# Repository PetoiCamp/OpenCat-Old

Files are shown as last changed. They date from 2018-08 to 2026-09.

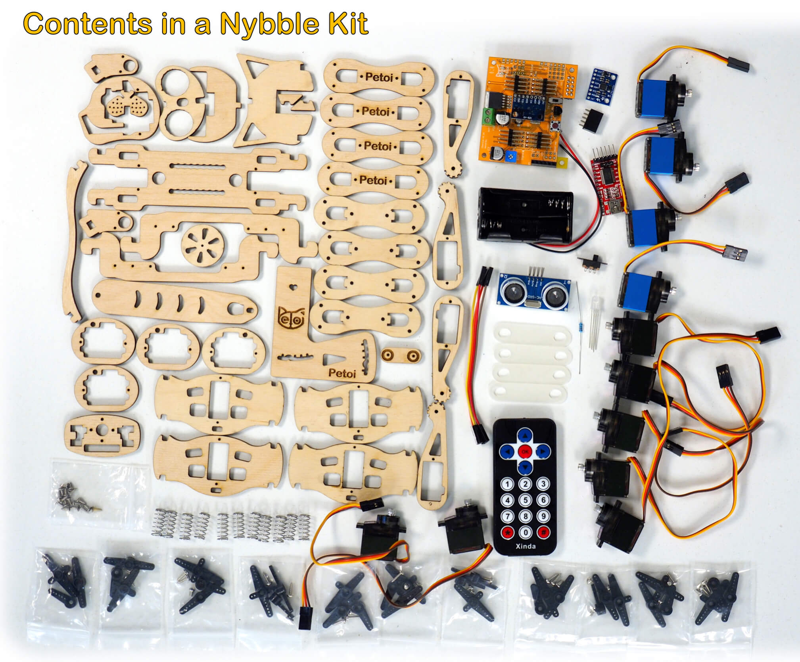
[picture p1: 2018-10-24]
Resource/Images/nybbleParts.jpg

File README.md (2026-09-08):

# OpenCat

**This repository for Nybble is too redundent with large image files and is now obsolete. Please visit our [new repository for OpenCat](https://github.com/PetoiCamp/OpenCat) that works for both Nybble and Bittle! For the latest OpenCat robots (Bittle X, Nybble Q), see [OpenCatESP32](https://github.com/PetoiCamp/OpenCatEsp32-Quadruped-Robot), or buy [Bittle X on Petoi.com](https://www.petoi.com/shop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).**





--

This is the repository for OpenCat project. 

The goal is to collaborate talents for this cute quadruped mini robot kit. It's still a complex system only for skilled makers, yet we want to share it with the public by mass production and bringing down the cost. 

OpenCat robots are used for hands-on **physical AI education** and real-world **physical AI applications** — from K-12 robotics classrooms to university research labs — not just screen-based coding exercises.

## Quaddle mini robot dog — launching on Kickstarter Sept 2, 2026


[Quaddle](https://www.kickstarter.com/projects/petoi/quaddle-open-source-desktop-robot-kit/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) is Petoi's newest quadruped, **going live on Kickstarter Sept 2, 2026** — a mini desk robot built on the same OpenCat lineage as Bittle and Nybble.

- Full quadruped running on just **4 servos** instead of the usual 8–12, which forces genuinely different gait-design and leg-coordination solutions to still get all four legs walking, running, and balancing
- Position-feedback servos — readable, not just drivable — which is what makes **Puppet Mode** possible: hand-guide the legs and record a motion directly, no code required
- 3D-printable shells and mounts for customization
- Same open platform this codebase's lineage already supports for gait research, reinforcement learning (RL), and sim2real work — a hands-on physical AI platform, not a toy version of the idea
- Try it in the [online simulator](https://www.petoi.com/pages/quaddle-robot-dog-simulator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) before it ships

**Source code is not yet public.** It's an upgraded version of the OpenCat project. Its ESP32-S3 code structure is closer to [OpenCatESP32](https://github.com/PetoiCamp/OpenCatEsp32-Quadruped-Robot), which already powers thousands of Bittle X and Nybble Q robots in the field, than to this legacy repo. We plan to open source it before Quaddle delivery.

- Watch [r/petoi](https://www.reddit.com/r/Petoi/) for the open-source announcement
- [Get notified on Kickstarter](https://www.kickstarter.com/projects/petoi/quaddle-open-source-desktop-robot-kit/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) when it goes live
- Check out the [Quaddle Hugging Face page](https://huggingface.co/petoi/quaddle)

## About the Founder & Track Record

Inspired by Boston Dynamics' Spot, [Dr. Rongzhong Li](https://www.linkedin.com/in/rongzhongli/) started OpenCat in his dorm at Wake Forest University in 2016. The goal was straightforward: make agile quadruped robots affordable and hackable enough for researchers, educators, and makers — not just well-funded labs.

Since then:
- **30,000+ robots shipped**, cumulative across all channels
- **60+ countries**
- **$1M+ raised** across two prior Kickstarter and Indiegogo campaigns
- **20+ academic papers** cite the platform — see [Research Spotlight](https://www.petoi.com/pages/robotics-research-and-academic-applications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)
- One of the most-starred open-source quadruped robot projects on GitHub

Follow the project:

- [YouTube](https://www.youtube.com/@petoicamp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)
- [Twitter](https://twitter.com/petoicamp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)
- [Instagram](https://www.instagram.com/petoicamp/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)
- [Facebook](https://www.facebook.com/PetoiCamp/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)
- [LinkedIn](https://www.linkedin.com/company/petoi/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)
- [TikTok](https://www.tiktok.com/@petoicamp/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)

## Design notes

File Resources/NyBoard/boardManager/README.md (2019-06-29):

# Arduino IDE Board Manager

Adds the NyBoard board definition through the *Arduino 1.6.4 (and later)* board manager rather then editing `boards.txt` directly as described at https://github.com/PetoiCamp/OpenCat/wiki/Software-setup.

## Usage

1. Open the Arduino IDE application

2. Open the `Preferences...` panel

3. In the `Additional Boards Manager URLs` field, add `https://raw.githubusercontent.com/PetoiCamp/OpenCat/master/Resources/NyBoard/boardManager/package_petoi_nyboard_index.json`. If there are already URLs listed in this field, separate them with commas or click on the icon next to the field to open up an editor and add this URL to a new line.

4. Click on the `OK` button to close the `Preferences...` panel (you may need to do this for the `Additional Boards Manager URLs` editor first, if you opened it up in the previous step)

5. Open the `Boards Manager...` window with the `Tools` -> `Board: XXXX` -> `Boards Manager...` menu item.

6. In the `Filter your search...` field, type `NyBoard`

7. Select the entry and click on `Install`

8. Click on the `Close` button

9. Select `ATmega328P (5V, 20 MHz) NyBoard` from the `Tools` -> `Board: XXXX` menu and enjoy!

## Updating the Board Definition

This section should not be necessary for most users and is included only for reference. As this is my first foray into using the Boards Manager, these steps may change slightly as necessary and I will try to keep this updated for reference.

1. Any additions to the `NyBoard-0.1` directory or changes to `NyBoard-0.1/boards.txt` require the following additional steps (update version numbers as appropriate):

  A. The archive file `NyBoard-0.1.x.tar.bz2` needs to be rebuilt

    i. Mac or Linux, use: `tar -cjf NyBoard-0.1.x.tar.bz2 NyBoard-0.1`

    ii. *TBD* need Windows equivalent

  B. Update `pacakge_petoi_nyboard_index.json` as follows:

    i. Update the `"version"` field to match the new version number (e.g. "0.1.x")

    ii. Update the `"url"` and `"archiveFileName"` fields to match the new archive name.

    iii. Update the `"size"` field to match the new archive file size

    iv. Update the `"checksum"` field to match the new archive file

      a. Mac or Linux use: `openssl dgst -sha256 NyBoard-0.1.x.tar.bz2` to get this value

      b. *TBD* need Windows equivalent

  C. Alternatively, if you wish to keep multiple versions of the board definition around, you can copy the entire entry in `"platforms"` (lines 12 - 31), add a comma after the closing brace of the last entry in `"platforms"`, paste the copy to the next line (before the closing bracket) and make the changes in **B** to the new entry.

2. Changes to the other informational fields of `pacakge_petoi_nyboard_index.json` should not require rebuilding the archive or modifying the file size or checksum values.

## Reference

* https://github.com/PetoiCamp/OpenCat/wiki/Software-setup
* https://github.com/arduino/Arduino/wiki/Arduino-IDE-1.6.x-package_index.json-format-specification

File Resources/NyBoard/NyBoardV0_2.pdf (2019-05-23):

## User Manual of NyBoard V0_2

Introduction

- NyBoard is a motion control board for the robotic kitten named Nybble, the first product of OpenCat project. It’s also compatible for other robots following OpenCat framework. Taking ATmega328P as the core processor, NyBoard runs at 20MHz clock to control 16 independent PWM servos with real-time adaption.
- The size of NyBoard is only 65×56mm. Components on the board are carefully laid out to precisely fit the contour of Raspberry Pi 3B and later models. There is a 2×5 socket connecting the NyBoard and Pi, which includes the power, UART, reset, I

2
C
and I²
C reference. Through it, the NyBoard can power Pi and communicate with Pi.
- NyBoard can accept 6~9V power inputs. Be careful with the polarity when connecting your power supply to NyBoard’s battery socket. There’s “+” and “-” besides the socket. Reversed connection may damage your NyBoard!
- To isolate voltage fluctuation caused by servos’ movement, NyBoard provides two independent power management. One supplies a stable 5V power to the chips, the other supplies an adjustable voltage (4.5-7.5V) to suit most models of servos. To ensure safety during operation, please do not connect the servo to NyBoard first. Check the rated voltage of the servo, use a voltmeter to monitor the output for servos and adjust the potentiometer to obtain a desired voltage.
- NyBoard has a built-in I²
C network with ATmeg328P working as master and other peripherals as slaves, including the PWM/servo driver, the 6-Axis motion sensor and external EEPROM. NyBoard also provides a jumper switch for users to choose whether ATmega328p or Pi (or another AI chip) will be the master of the I² C
network. We hope that by providing alternatives, users can explore and find the best configuration for their projects.

Features

- Core processor: ATmega328P working at the frequency of 20MHz.
- Power input: DC 6-9V
- Power output: Two independent power supplies, 5V to chips (3A peak), 4.5-7.5V adjustable voltage to servos (5A peak). Dial counterclockwise will increase the voltage for servos. The stable voltage range will shift with different input voltage. Due to the resistance in chip, the maximum output will be lower than raw input. Stable 7.5V can only be achieved with 9V input. Try to use the lowest voltage that can complete your motion requirement, to reduce the wearing of your servo’s gears, and increase both circuit stability and battery life.

- On NyBoard V0_2, there’s a jumper switch (SW3). You can choose to power the metal servos included in Nybble kit by batteries directly to achieve the best performance. Don’t power cheap plastic servos directly by battery!
- LED power indicators: 2 LEDs, blue for the chip, yellow for the servos.
- Servo: 16 channel PWM outputs.
- Grouped 2x3 SPI port for burning bootloader or uploading sketches.
- FTDI port: 1×6 socket for connecting the 5V serial-to-USB translator. The long pin legs allow bending to the other side of the board or other directions for convenient access.
- Motion sensor port: connects to GY521-MPU6050, which is centered on the board. Interrupt is connected to pin D2. Note: MPU6050 should always be facing up for measurements using default library (I2Cdevlib).
- 2×5 Socket to Pi: connects to 5V power, I²
C, I

2
C reference, 3.3V UART and reset.
- I

2

C switch (SW2): choose ATmega328P or Pi as the master of the I²
C network.
Note that the REF pin in the 2x5 socket must be connected to the Vcc of the master board as a reference for the level converter chip.
- Additional I²
C ports: 3x I

2
C ports directly connected to the 2x5 socket of Pi, leveled at 3.3V. (It’s not connected to the ATmega328 ’s I

2
C network)
- EEPROM: 8KB. Page write limit is 32 Bytes.
- Additional D/A pins: 3×4 socket with unused pins of ATmega328P
- Additional 5V/GND pins: power other peripherals
- Additional capacitor port below C3: allow more stable output for intense motion
- IR receiver: Receiving frequency 38KHz (using Arduino digital pin D4). The long pins allow bending to the best receiving orientation.
- Buzzer: Active (using Arduino PWM pin D5)
- Reset button: Reset the NyBoard
- Battery voltage detector: can be programed to alarm when battery is low (using Arduino analog pin ADC0)
- PCB: double-layer, 65×56mm

Ports and Specification

The tables are ordered as the squares on the board, from left to right, top to bottom:

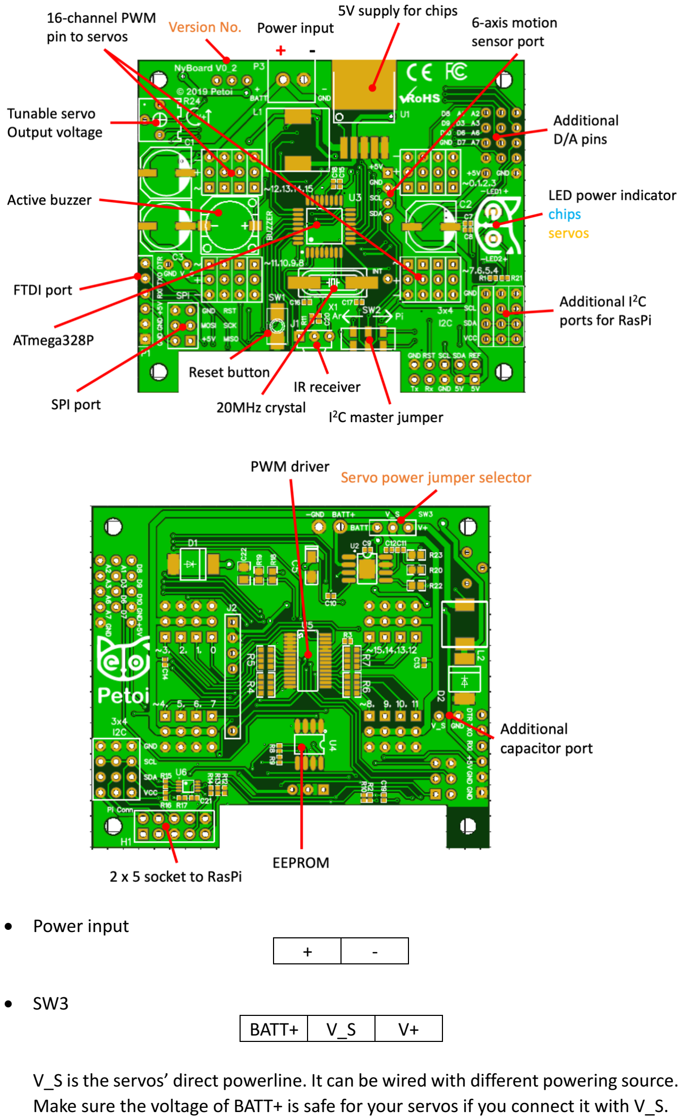
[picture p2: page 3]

- Power input
+ -
- SW3
BATT+ | V_S | V+

V_S is the servos’ direct powerline. It can be wired with different powering source. Make sure the voltage of BATT+ is safe for your servos if you connect it with V_S.

V+ comes from the stepdown chip. It has regulated but limited output.

- 16 channel PWM pin to servos (NyBoard V0_2)
GND | | GND
+ | | +
12 | 13 | 14 | 15 | 0 | 1 | 2 | 3
11 | 10 | 9 | 8 | 7 | 6 | 5 | 4
+ | | | | +
GND | | | | GND
- FTDI port
DTR
TXO
RXI
+5V
GND
GND
- SPI port
GND | RST
MOSI | SCK
+5V | MISO
- IR receiver
OUT | GND | +5V
- 6-Axis motion sensor port
Mark on NyBoard | Corresponding pins on GY521
+5V | VCC
GND | GND
SCL | SCL
SDA | SDA
/ | /
/ | /
/ | /
INT | INT
- I

2
C jumper switch
Dial up to select ATmega328P, dial down to select Pi (or another AI chip)

- Pre-defined pins (~ supports PWM)
Interrupt | IR receiver | Buzzer | MOSI | MISO | SCK
D2 | D4 | D5 ~ | D11 ~ | D12 | D13
- Additional D/A pins
D8 | ADC1 | ADC2
D9 ~ | D3 ~ | ADC3
D10 ~ | D6 ~ | ADC6
GND | D7 | ADC7
+5V | | GND
Recommended usage is using (D8, D9, D10, GND) for the ultrasound sensor, and (A2, A3, A6, A7) for optional foot contact sensors. You can also find other combinations in one row/column for convenient interfacing (2 Digital + 1 Analog, 2 Analog + 1 Digital, GND + digital + Analog, etc.)
- Additional I²
C ports (the voltage of VCC is equal to REF)
GND | GND | GND
SCL_P | SCL_P | SCL_P
SDA_P | SDA_P | SDA_P
VCC | VCC | VCC
- Socket to Pi
REF | SDA_P | SCL_P | RST | GND
+5V | +5V | GND | TXD | RXD

May 21st, 2019

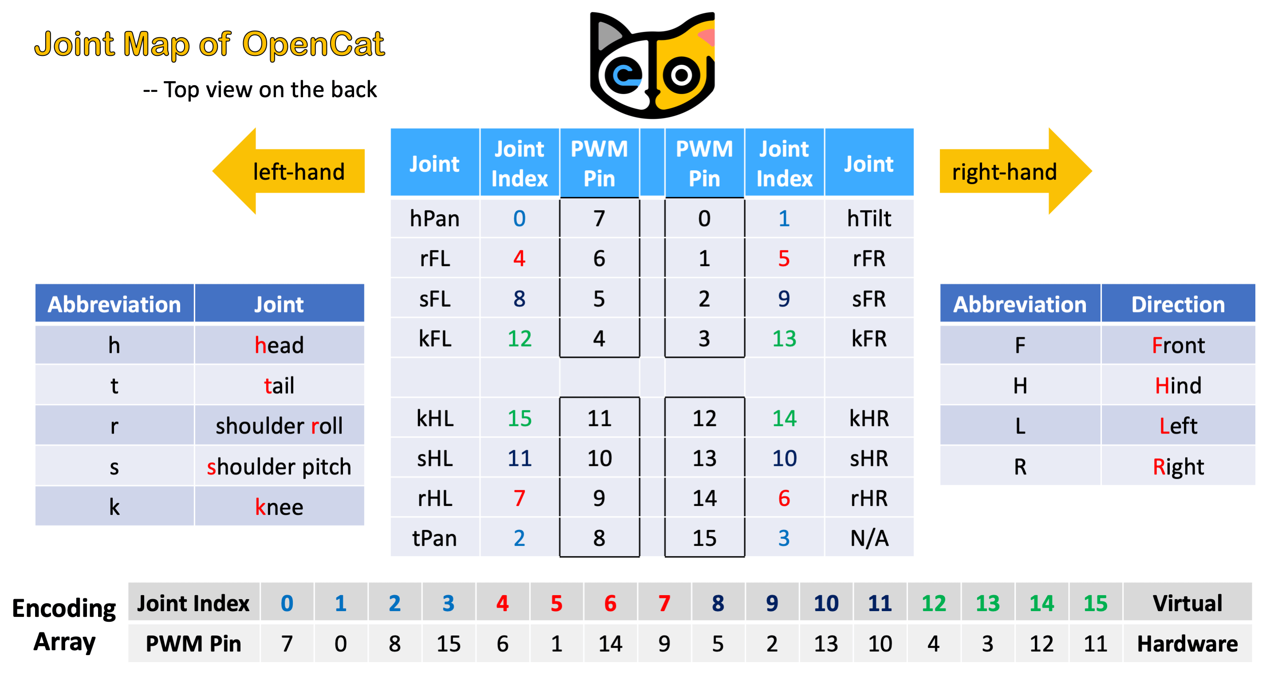
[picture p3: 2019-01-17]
Resources/Images/jointMap.png

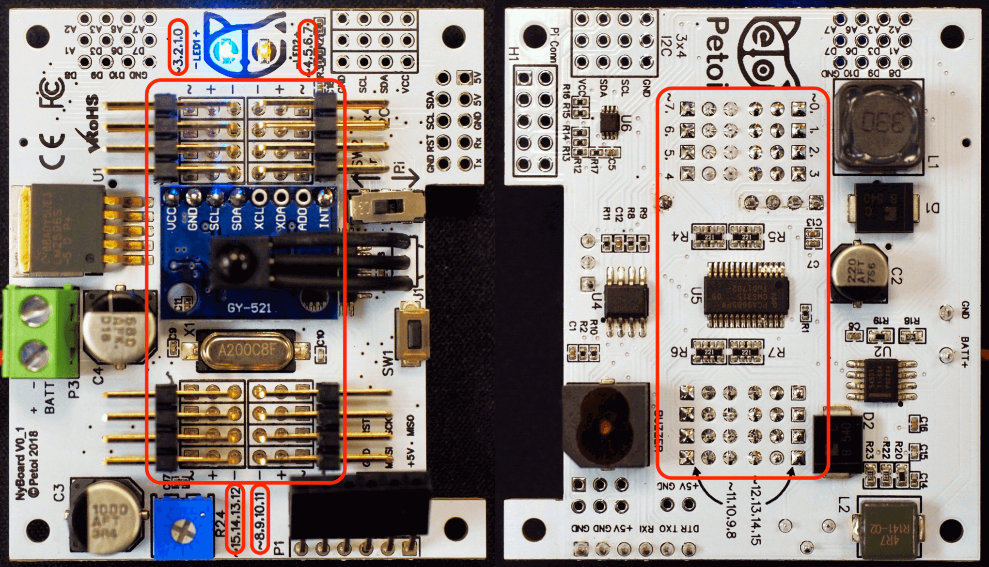
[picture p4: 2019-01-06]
Resources/Images/v0_1.png

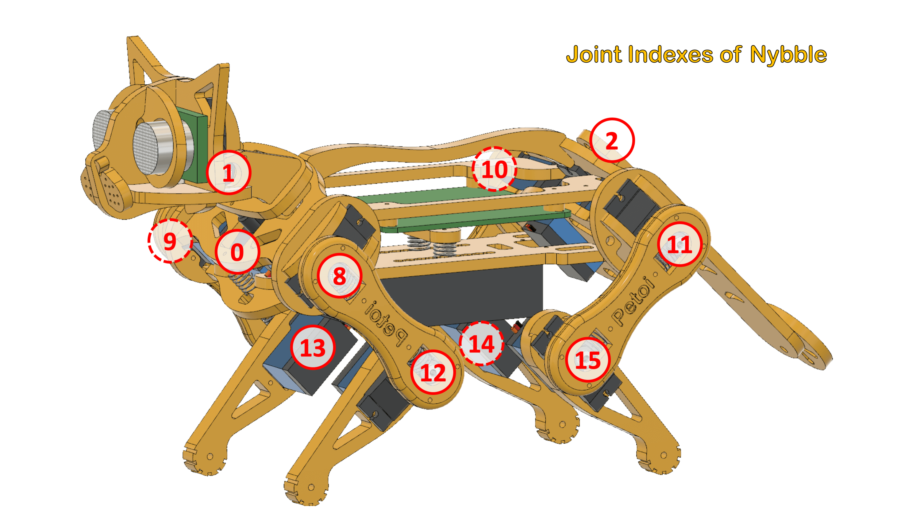
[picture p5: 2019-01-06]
Resources/Images/jointIndexNybble.png

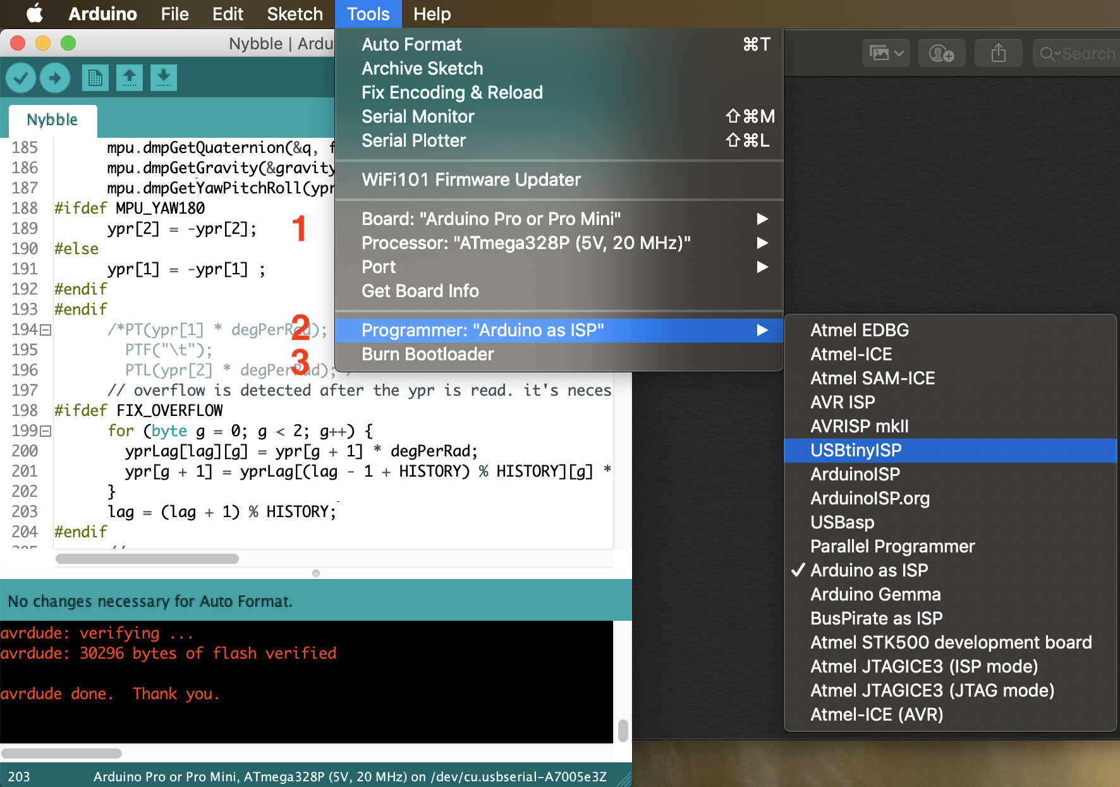
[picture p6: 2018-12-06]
Resources/Images/burnBootloader.png

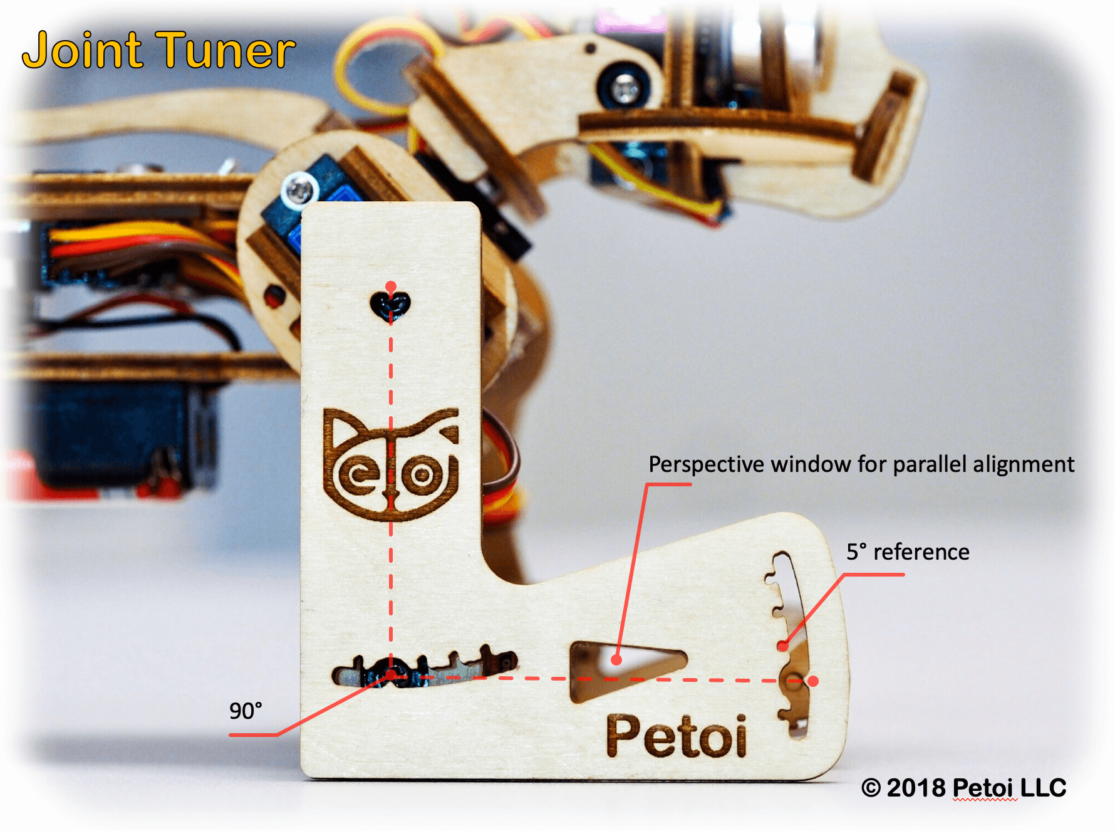
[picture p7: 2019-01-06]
Resources/Images/LTuner.png

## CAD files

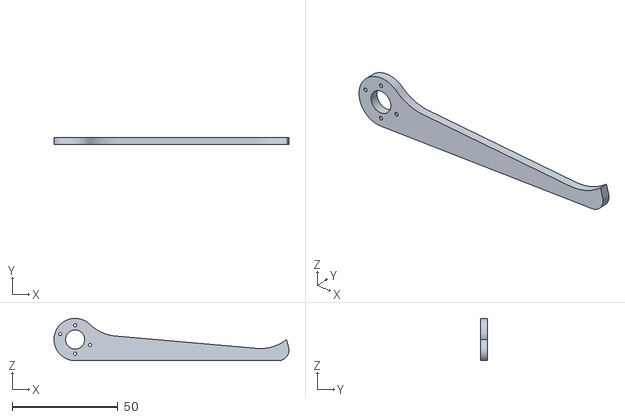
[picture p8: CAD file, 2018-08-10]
ModuleTests/testServo/servoTorqueArm.stl
111.2 x 3.50 x 20.0

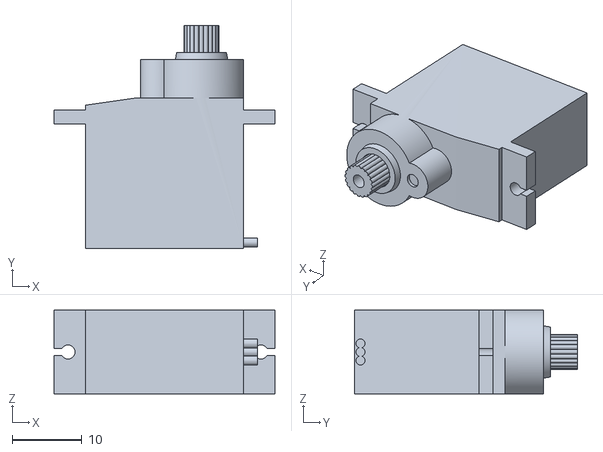
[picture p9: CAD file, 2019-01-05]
Resources/STL/mg90d.stl
31.6 x 31.9 x 12.0

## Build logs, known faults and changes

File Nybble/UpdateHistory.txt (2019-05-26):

Update History
-------------------------
May.25, 2019
* OpenCat.h
- Changed printList() to concatenate strings before printing them to serial. Reduced communication. 

* ardSerial
- Implemented serial communicator in Python on the Pi side. Almost equivalent to Arduino IDE's serial monitor. 

May.23, 2019

* Nybble.ino
- Implemented serial parser for token 'i' and 'l'.
- Converted the serial parser from if...else to switch cases.
- Updated serialProtocol.png for the actual codes of 'i' and 'l'.
- Lowered the battery voltage watcher's threshold.
- Changed the pin "0" in attachInterrupt() to "#define INTERRUPT 0" in OpenCat.h.

May. 4, 2019

* Nybble.ino
- Added a new token 'j' to show the list of current joint angles. 
  It can be used after multiple 'm' commands to define a new posture. 
- Added a key ("tb" on remote) to turn off the Gyro and boost running speed for 4 cycles.
- Added a greeting behavior ("hi" on remote).

Apr.22, 2019

*Nybble.ino
- Added offsetLR and related logic to let Nybble look around when walking and turning
- Added battery voltage reading at the beginning of loop().
  If the voltage drops below certain value, the program will pause by meow() to recharges the capacitor.
  It will reduce the abnormal rotation of servos and chances of board reset.
- Redefined the key map of infrared remote.

* OpenCat.h
- Added preprocessor #DEVELOPER to hide some detailed debugging information and libraries.
- Moved "#define NYBBLE" from OpenCat.h to Instinct.h 
- Changed yprLag from int8_t (angles) to float (radian) to reduce calculations for degree/radian conversion
- Changed RollPitchDeviation from int8_t (angles) to float (radian).
- Changed the type of adaptiveParameterArray from float to int8_t. Adjusted values.

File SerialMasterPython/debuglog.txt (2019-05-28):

Testing command-line inputs

    ./ardserial.py c->works

    ./ardserial.py c15-> gives c1   5..which might be a problem

    ./ardserial.py m1 75, m 1 75 also work

    ./ardserial.py u-> works

    ./ardSerial.py i 1 9 9 13 13 1-> works

    ./ardserial.py u 0 7->works

Testing wrapper() with schedule

    The cases with ints arrays work

    Single letter cases seem to work (although things 'ktr' and 'c8' might have issues)

    string arrays might be an issues

    Even though the last process is a d, the light doesnt turn off.

    Beep works

There might be a bug in 'k'

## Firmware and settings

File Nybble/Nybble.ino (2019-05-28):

/* Main Arduino sketch for Nybble, the walking robot kitten.
   Updates should be posted on GitHub: https://github.com/PetoiCamp/OpenCat

   Rongzhong Li
   Aug. 27, 2018
   Copyright (c) 2018 Petoi LLC.

   This sketch may also includes others' codes under MIT or other open source liscence.
   Check those liscences in corresponding module test folders.
   Feel free to contact us if you find any missing references.

   The MIT License

  Permission is hereby granted, free of charge, to any person obtaining a copy
  of this software and associated documentation files (the "Software"), to deal
  in the Software without restriction, including without limitation the rights
  to use, copy, modify, merge, publish, distribute, sublicense, and/or sell
  copies of the Software, and to permit persons to whom the Software is
  furnished to do so, subject to the following conditions:
  The above copyright notice and this permission notice shall be included in all
  copies or substantial portions of the Software.
  THE SOFTWARE IS PROVIDED "AS IS", WITHOUT WARRANTY OF ANY KIND, EXPRESS OR
  IMPLIED, INCLUDING BUT NOT LIMITED TO THE WARRANTIES OF MERCHANTABILITY,
  FITNESS FOR A PARTICULAR PURPOSE AND NONINFRINGEMENT. IN NO EVENT SHALL THE
  AUTHORS OR COPYRIGHT HOLDERS BE LIABLE FOR ANY CLAIM, DAMAGES OR OTHER
  LIABILITY, WHETHER IN AN ACTION OF CONTRACT, TORT OR OTHERWISE, ARISING FROM,
  OUT OF OR IN CONNECTION WITH THE SOFTWARE OR THE USE OR OTHER DEALINGS IN THE
  SOFTWARE.
*/
#define MAIN_SKETCH
#include "WriteInstinct/OpenCat.h"

#include <I2Cdev.h>
#include <MPU6050_6Axis_MotionApps20.h>


#define PACKET_SIZE 42
#define OVERFLOW_THRESHOLD 128

//#if OVERFLOW_THRESHOLD>1024-1024%PACKET_SIZE-1   // when using (1024-1024%PACKET_SIZE) as the overflow resetThreshold, the packet buffer may be broken
// and the reading will be unpredictable. it should be replaced with previous reading to avoid jumping
#define FIX_OVERFLOW
//#endif
#define HISTORY 2
int8_t lag = 0;
float ypr[3];         // [yaw, pitch, roll]   yaw/pitch/roll container and gravity vector
float yprLag[HISTORY][2];

MPU6050 mpu;
#define OUTPUT_READABLE_YAWPITCHROLL
// MPU control/status vars
bool dmpReady = false;  // set true if DMP init was successful
uint8_t mpuIntStatus;   // holds actual interrupt status byte from MPU
uint8_t devStatus;      // return status after each device operation (0 = success, !0 = error)
uint16_t packetSize;    // expected DMP packet size (default is 42 bytes)
uint16_t fifoCount;     // count of all bytes currently in FIFO
uint8_t fifoBuffer[PACKET_SIZE]; // FIFO storage buffer

// orientation/motion vars
Quaternion q;           // [w, x, y, z]         quaternion container
VectorFloat gravity;    // [x, y, z]            gravity vector

// ================================================================
// ===               INTERRUPT DETECTION ROUTINE                ===
// ================================================================

volatile bool mpuInterrupt = false;     // indicates whether MPU interrupt pin has gone high
void dmpDataReady() {
  mpuInterrupt = true;
}

// https://brainy-bits.com/blogs/tutorials/ir-remote-arduino
#include <IRremote.h>

/*-----( Declare objects )-----*/
IRrecv irrecv(IR_RECIEVER);     // create instance of 'irrecv'
decode_results results;      // create instance of 'decode_results'
String translateIR() // takes action based on IR code received
// describing Remote IR codes.
{
  switch (results.value) {
      //IR signal    key on IR remote       //abbreviation of gaits   //gait/posture names
#ifdef DEVELOPER

    case 0xFFA25D: PTLF(" CH-");          return (F("sit"));
    case 0xFF629D: PTLF(" CH");           return (F("d"));          //shutdown all servos
    case 0xFFE21D: PTLF(" CH+");          return (F("hi"));        //greetings


    case 0xFF22DD: PTLF(" |<<");          return (F("buttUp"));     //butt up
    case 0xFF02FD: PTLF(" >>|");          return (F("balance"));    //neutral standing
    case 0xFFC23D: PTLF(" >||");          return (F("str"));        //stretch

    case 0xFFE01F: PTLF(" -");            return (F("pee"));         //
    case 0xFFA857: PTLF(" +");            return (F("tr"));         //trot
    case 0xFF906F: PTLF(" EQ");           return (F("pu"));         // push up

    case 0xFF6897: PTLF(" 0");            return (F("wkL"));        //walk left
    case 0xFF9867: PTLF(" 100+");         return (F("wk"));         //walk
    case 0xFFB04F: PTLF(" 200+");         return (F("wkR"));        //walk right

    case 0xFF30CF: PTLF(" 1");            return (F("crL"));        //crawl left
    case 0xFF18E7: PTLF(" 2");            return (F("cr"));         //crawl fast
    case 0xFF7A85: PTLF(" 3");            return (F("crR"));        //crawl right

    case 0xFF10EF: PTLF(" 4");            return (F("bkL"));        // back left
    case 0xFF38C7: PTLF(" 5");            return (F("bk"));         //back
    case 0xFF5AA5: PTLF(" 6");            return (F("bkR"));        //back right

    case 0xFF42BD: PTLF(" 7");            return (F("tb"));      //turbo
    case 0xFF4AB5: PTLF(" 8");            return (F("zero"));       //customed skill
    case 0xFF52AD: PTLF(" 9");            return (F("rc"));       //recover (turtle roll )
#else
    case 0xFFA25D:                        return (F("sit"));
    case 0xFF629D:                        return (F("d"));          //shutdown all servos
    case 0xFFE21D:                        return (F("hi"));        //greetings


    case 0xFF22DD:                        return (F("buttUp"));     //butt up
    case 0xFF02FD:                        return (F("balance"));    //neutral standing
    case 0xFFC23D:                        return (F("str"));        //stretch

    case 0xFFE01F:                        return (F("pee"));         //
    case 0xFFA857:                        return (F("tr"));         //trot
    case 0xFF906F:                        return (F("pu"));         // push up

    case 0xFF6897:                        return (F("wkL"));        //walk left
    case 0xFF9867:                        return (F("wk"));         //walk
    case 0xFFB04F:                        return (F("wkR"));        //walk right

    case 0xFF30CF:                        return (F("crL"));        //crawl left
    case 0xFF18E7:                        return (F("cr"));         //crawl fast
    case 0xFF7A85:                        return (F("crR"));        //crawl right

    case 0xFF10EF:                        return (F("bkL"));        // back left
    case 0xFF38C7:                        return (F("bk"));         //back
    case 0xFF5AA5:                        return (F("bkR"));        //back right

    case 0xFF42BD:                        return (F("tb"));      //turbo
    case 0xFF4AB5:                        return (F("zero"));       //customed skill
    case 0xFF52AD:                        return (F("rc"));       //recover (turtle roll )
#endif

    case 0xFFFFFFFF: return (""); //Serial.println(" REPEAT");

    default: {
        Serial.println(results.value, HEX);
      }
      return ("");                      //Serial.println("null");
  }// End Case
  //delay(100); // Do not get immediate repeat //no need because the main loop is slow

  // The control could be organized in another way, such as:
  // forward/backward to change the gaits corresponding to different speeds.
  // left/right key for turning left and right
  // number keys for different postures or behaviors
}


char token;
#define CMD_LEN 10
char *lastCmd = new char[CMD_LEN];
char *newCmd = new char[CMD_LEN];
byte newCmdIdx = 0;
byte hold = 0;
int8_t offsetLR = 0;
bool checkGyro = true;
int8_t countDown = 0;

uint8_t timer = 0;
//#define SKIP 1
#ifdef SKIP
byte updateFrame = 0;
#endif
byte firstMotionJoint;
byte jointIdx = 0;


unsigned long usedTime = 0;

void checkBodyMotion()  {
  if (!dmpReady) return;
  // wait for MPU interrupt or extra packet(s) available
  //while (!mpuInterrupt && fifoCount < packetSize) ;
  if (mpuInterrupt || fifoCount >= packetSize)
  {
    // reset interrupt flag and get INT_STATUS byte
    mpuInterrupt = false;
    mpuIntStatus = mpu.getIntStatus();

    // get current FIFO count
    fifoCount = mpu.getFIFOCount();
    //PTL(fifoCount);
    // check for overflow (this should never happen unless our code is too inefficient)
    if ((mpuIntStatus & 0x10) || fifoCount > OVERFLOW_THRESHOLD) { //1024) {
      // reset so we can continue cleanly
      mpu.resetFIFO();
      // otherwise, check for DMP data ready interrupt (this should happen frequently)

      // -- RzLi --
#ifdef FIX_OVERFLOW
#ifdef DEVELOPER
      PTLF("FIFO overflow! Using last reading!");
#endif
      lag = (lag - 1 + HISTORY) % HISTORY;
#endif
      // --
    }
    else if (mpuIntStatus & 0x02) {
      // wait for correct available data length, should be a VERY short wait
      while (fifoCount < packetSize) fifoCount = mpu.getFIFOCount();

      // read a packet from FIFO
      mpu.getFIFOBytes(fifoBuffer, packetSize);

      // track FIFO count here in case there is > 1 packet available
      // (this lets us immediately read more without waiting for an interrupt)
      fifoCount -= packetSize;

#ifdef OUTPUT_READABLE_YAWPITCHROLL
      // display Euler angles in degrees
      mpu.dmpGetQuaternion(&q, fifoBuffer);
      mpu.dmpGetGravity(&gravity, &q);
      mpu.dmpGetYawPitchRoll(ypr, &q, &gravity);
#ifdef MPU_YAW180
      ypr[2] = -ypr[2];
#else
      ypr[1] = -ypr[1] ;
#endif
#endif
      /*PT(ypr[1] * degPerRad);
        PTF("\t");
        PTL(ypr[2] * degPerRad);*/
      // overflow is detected after the ypr is read. it's necessary to keep a lag recrod of previous reading.  -- RzLi --
#ifdef FIX_OVERFLOW
      for (byte g = 0; g < 2; g++) {
        yprLag[lag][g] = ypr[g + 1];
        ypr[g + 1] = yprLag[(lag - 1 + HISTORY) % HISTORY][g] ;
      }
      lag = (lag + 1) % HISTORY;
#endif
      // --
      //deal with accidents
      if (fabs(ypr[1])*degPerRad > LARGE_PITCH) {
#ifdef DEVELOPER
        PT(ypr[1] * degPerRad);
        PTF("\t");
        PTL(ypr[2] * degPerRad);
#endif
        if (!hold) {
          token = 'k';
          strcpy(newCmd, ypr[1]*degPerRad > LARGE_PITCH ? "lifted" : "dropped");
          newCmdIdx = 1;
        }
        hold = 10;
      }
      // recover
      else if (hold) {
        if (hold == 10) {
          token = 'k';
          strcpy(newCmd, "balance");
          newCmdIdx = 1;
        }
        hold --;
        if (!hold) {
          char temp[CMD_LEN];
          strcpy(temp, newCmd);
          strcpy(newCmd, lastCmd);
          strcpy(lastCmd, temp);
          newCmdIdx = 1;
          meow();
        }
      }
      //calculate deviation
      for (byte i = 0; i < 2; i++) {
        RollPitchDeviation[i] = ypr[2 - i] - motion.expectedRollPitch[i];
        //PTL(RollPitchDeviation[i]);
        RollPitchDeviation[i] = sign(ypr[2 - i]) * max(fabs(RollPitchDeviation[i]) - levelTolerance[i], 0);//filter out small angles
      }
      //PTL(jointIdx);
    }
  }
}

void setup() {
  pinMode(BUZZER, OUTPUT);
  // join I2C bus (I2Cdev library doesn't do this automatically)
#if I2CDEV_IMPLEMENTATION == I2CDEV_ARDUINO_WIRE
  Wire.begin();
  //Wire.setClock(400000);
  TWBR = 24; // 400kHz I2C clock (200kHz if CPU is 8MHz)
#elif I2CDEV_IMPLEMENTATION == I2CDEV_BUILTIN_FASTWIRE
  Fastwire::setup(400, true);
#endif

  Serial.begin(57600);
  Serial.setTimeout(10);
  while (!Serial);
  // wait for ready
  while (Serial.available() && Serial.read()); // empty buffer
  delay(100);
  PTLF("\n* Start *");
  PTLF("Initialize I2C");
  PTLF("Connect MPU6050");
  mpu.initialize();
  //do
  {
    delay(500);
    // verify connection
    PTLF("Test connection");
    PTL(mpu.testConnection() ? F("MPU successful") : F("MPU failed"));//sometimes it shows "failed" but is ok to bypass.
  } //while (!mpu.testConnection());

  // load and configure the DMP
  do {
    PTLF("Initialize DMP");
    devStatus = mpu.dmpInitialize();
    delay(500);
    // supply your own gyro offsets here, scaled for min sensitivity

    for (byte i = 0; i < 4; i++) {
      PT(EEPROMReadInt(MPUCALIB + 4 + i * 2));
      PT(" ");
    }
    PTL();
    mpu.setZAccelOffset(EEPROMReadInt(MPUCALIB + 4));
    mpu.setXGyroOffset(EEPROMReadInt(MPUCALIB + 6));
    mpu.setYGyroOffset(EEPROMReadInt(MPUCALIB + 8));
    mpu.setZGyroOffset(EEPROMReadInt(MPUCALIB + 10));
    // make sure it worked (returns 0 if so)
    if (devStatus == 0) {
      // turn on the DMP, now that it's ready
      PTLF("Enable DMP");
      mpu.setDMPEnabled(true);

      // enable Arduino interrupt detection
      PTLF("Enable interrupt");
      attachInterrupt(INTERRUPT, dmpDataReady, RISING);
      mpuIntStatus = mpu.getIntStatus();

      // set our DMP Ready flag so the main loop() function knows it's okay to use it
      PTLF("DMP ready!");
      dmpReady = true;

      // get expected DMP packet size for later comparison
      packetSize = mpu.dmpGetFIFOPacketSize();
    } else {
      // ERROR!
      // 1 = initial memory load failed
      // 2 = DMP configuration updates failed
      // (if it's going to break, usually the code will be 1)
      PTLF("DMP failed (code ");
      PT(devStatus);
      PTLF(")");
      PTL();
    }
  } while (devStatus);

  //opening music
#if WALKING_DOF == 8
  playMelody(MELODY);
#endif

  //IR
  {
    //PTLF("IR Receiver Button Decode");
    irrecv.enableIRIn(); // Start the receiver
  }

  assignSkillAddressToOnboardEeprom();
  PTL();

  // servo
  { pwm.begin();

    pwm.setPWMFreq(60 * PWM_FACTOR); // Analog servos run at ~60 Hz updates
    delay(200);

    //meow();
    strcpy(lastCmd, "rest");
    motion.loadBySkillName("rest");
    for (int8_t i = DOF - 1; i >= 0; i--) {
      pulsePerDegree[i] = float(PWM_RANGE) / servoAngleRange(i);
      servoCalibs[i] = servoCalib(i);
      calibratedDuty0[i] =  SERVOMIN + PWM_RANGE / 2 + float(middleShift(i) + servoCalibs[i]) * pulsePerDegree[i]  * rotationDirection(i) ;
      //PTL(SERVOMIN + PWM_RANGE / 2 + float(middleShift(i) + servoCalibs[i]) * pulsePerDegree[i] * rotationDirection(i) );
      calibratedPWM(i, motion.dutyAngles[i]);
      delay(100);
    }
    randomSeed(analogRead(0));//use the fluctuation of voltage caused by servos as entropy pool
    shutServos();
    token = 'd';
  }
  beep(30);

  pinMode(BATT, INPUT);
  pinMode(VCC, OUTPUT);
  pinMode(TRIGGER, OUTPUT); // Sets the trigPin as an Output
  pinMode(ECHO, INPUT); // Sets the echoPin as an Input
  digitalWrite(VCC, HIGH);
  int t = 0;
  int minDist, maxDist;
  while (0) {//disabled for now. needs virtual threading to reduce lag in motion.
    calibratedPWM(0, -10 * cos(t++*M_PI / 360));
    calibratedPWM(1, 10 * sin(t++ * 2 * M_PI / 360));
    digitalWrite(TRIGGER, LOW);
    delayMicroseconds(2);

    // Sets the trigPin on HIGH state for 10 micro seconds
    digitalWrite(TRIGGER, HIGH);
    digitalWrite(BUZZER, HIGH);
    delayMicroseconds(10);
    digitalWrite(TRIGGER, LOW);
    digitalWrite(BUZZER, LOW);

    // Reads the echoPin, returns the sound wave travel time in microseconds

    long duration = pulseIn(ECHO, HIGH, farTime);

    // Calculating the distance

    int distance = duration * 0.034 / 2; // 10^-6 * 34000 cm/s

    // Prints the distance on the Serial Monitor
    Serial.print("Distance: ");
    Serial.print(distance == 0 ? LONGEST_DISTANCE : distance);
    Serial.println(" cm");
  }
  meow();
}
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

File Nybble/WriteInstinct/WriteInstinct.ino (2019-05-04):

 /*
    Instincts trained by Rongzhong
    Save calibration data and constants to EEPROM

    This sketch may also includes others' codes under MIT or other open source liscence.
    Check those liscences in corresponding module test folders.
    Feel free to contact us if you find any missing references.

    Rongzhong Li
    Oct 23, 2018
    Copyright (c) 2018 Petoi LLC.

   The MIT License

  Permission is hereby granted, free of charge, to any person obtaining a copy
  of this software and associated documentation files (the "Software"), to deal
  in the Software without restriction, including without limitation the rights
  to use, copy, modify, merge, publish, distribute, sublicense, and/or sell
  copies of the Software, and to permit persons to whom the Software is
  furnished to do so, subject to the following conditions:
  The above copyright notice and this permission notice shall be included in all
  copies or substantial portions of the Software.
  THE SOFTWARE IS PROVIDED "AS IS", WITHOUT WARRANTY OF ANY KIND, EXPRESS OR
  IMPLIED, INCLUDING BUT NOT LIMITED TO THE WARRANTIES OF MERCHANTABILITY,
  FITNESS FOR A PARTICULAR PURPOSE AND NONINFRINGEMENT. IN NO EVENT SHALL THE
  AUTHORS OR COPYRIGHT HOLDERS BE LIABLE FOR ANY CLAIM, DAMAGES OR OTHER
  LIABILITY, WHETHER IN AN ACTION OF CONTRACT, TORT OR OTHERWISE, ARISING FROM,
  OUT OF OR IN CONNECTION WITH THE SOFTWARE OR THE USE OR OTHER DEALINGS IN THE
  SOFTWARE.
*/
#include "OpenCat.h"
#define INSTINCT_SKETCH

void saveMPUcalib(int * var) {
  for (byte i = 0; i < 6; i++)
    EEPROM.update(MPUCALIB + i, var[i]);
}

void writeConst() {
  EEPROM.update(MELODY, sizeof(melody));
  for (byte i = 0; i < sizeof(melody); i++)
    EEPROM.update(MELODY - 1 - i, melody[i]);
  PTLF("Reset joint calibration? (Y/n)");
  while (!Serial.available());
  char resetJointCalibrationQ = Serial.read();
  for (byte i = 0; i < DOF; i++) {
    if (resetJointCalibrationQ == 'Y')
      EEPROM.update(CALIB + i, calibs[i]);
    EEPROM.update(PIN + i, pins[i]);
    EEPROM.update(MID_SHIFT + i, middleShifts[i]);
    EEPROM.update(ROTATION_DIRECTION + i, rotationDirections[i]);
    EEPROM.update(SERVO_ANGLE_RANGE + i, servoAngleRanges[i]);
    for (byte para = 0; para < NUM_ADAPT_PARAM; para++) {
      EEPROM.update(ADAPT_PARAM + i * NUM_ADAPT_PARAM + para, round(adaptiveParameterArray[i][para]));
    }
    /*PT(servoCalib(i));
      PT(',');*/
  }
  //PTL();
}
void saveSkillInfoFromProgmemToOnboardEeprom() {
  int skillAddressShift = 0;
  unsigned int i2cEepromAddress = 0; //won't hurt if unused
#ifdef I2C_EEPROM
  PTLF("\n* Update Instincts? (Y/n)");
  while (!Serial.available());
  char choice = Serial.read();
  PT(choice == 'Y' ? "Will" : "Won't");
  PTL(" overwrite Instincts on external I2C EEPROM!");
#endif
  PTLF("Saving skill info...");
  for (byte s = 0; s < NUM_SKILLS; s++) {//save skill info to on-board EEPROM
    byte len = strlen(skillNameWithType[s]);
    EEPROM.update(SKILLS + skillAddressShift++, len - 1); //the last char in name denotes skill type, I(nstinct) on external eeprom, N(ewbility) on progmem
    PT(skillNameWithType[s][len - 1] == 'I' ? "I nstinct:\t" : "N ewbility:\t");
    for (byte l = 0; l < len; l++) {
      PT(skillNameWithType[s][l]);
      EEPROM.update(SKILLS + skillAddressShift++, skillNameWithType[s][l]);
    }
    PTL();
    //PTL("Current EEPROM address is " + String(SKILLS + skillAddressShift));
#ifdef I2C_EEPROM
    if (!EEPROMOverflow)
      if (skillNameWithType[s][len - 1] == 'I' && choice == 'Y') { //  if there's instinct and there's i2c eeprom, and user decide to update.
        // save the data array to i2c eeprom. its address will be saved to onboard eeprom
        EEPROMWriteInt(SKILLS + skillAddressShift, i2cEepromAddress);
        copyDataFromPgmToI2cEeprom(i2cEepromAddress,  (unsigned int) progmemPointer[s]);
      }
#endif
    skillAddressShift += 2; // one int (2 bytes) for address
  }
  PTLF("  *********** Notice! *********");
  PTLF("    Maximal storage of onboard EEPROM is 1024 bytes.");
  PTF("\tInstinctive dictionary used ");
  PT(SKILLS + skillAddressShift);
  PT(" bytes (");
  PT(float(100) * (SKILLS + skillAddressShift) / 1024);
  PTLF(" %)!");
#ifdef I2C_EEPROM
  if (choice == 'Y') {
    PTF("    Maximal storage of external I2C EEPROM is ");
    PT(EEPROM_SIZE);
    PTLF(" bytes.");
    PT("\tInstinctive data used ");
    PT(i2cEepromAddress);
    PT(" bytes (");
    PT(float(100)*i2cEepromAddress / EEPROM_SIZE);
    PTLF(" %)!");
  }
#endif
  PTLF("  *****************************");
  PTLF("Finished!");
}

// the following MPU calibration codes are modified based on http://wired.chillibasket.com/2015/01/calibrating-mpu6050/
// Rongzhong Li
// Sep 16, 2018

// Arduino sketch that returns calibration offsets for MPU6050
//   Version 1.1  (31th January 2014)
// Done by Luis Ródenas <luisrodenaslorda@gmail.com>
// Based on the I2Cdev library and previous work by Jeff Rowberg <jeff@rowberg.net>
// Updates (of the library) should (hopefully) always be available at https://github.com/jrowberg/i2cdevlib

// These offsets were meant to calibrate MPU6050's internal DMP, but can be also useful for reading sensors.
// The effect of temperature has not been taken into account so I can't promise that it will work if you
// calibrate indoors and then use it outdoors. Best is to calibrate and use at the same room temperature.

/* ==========  LICENSE  ==================================
  I2Cdev device library code is placed under the MIT license
  Copyright (c) 2011 Jeff Rowberg

  Permission is hereby granted, free of charge, to any person obtaining a copy
  of this software and associated documentation files (the "Software"), to deal
  in the Software without restriction, including without limitation the rights
  to use, copy, modify, merge, publish, distribute, sublicense, and/or sell
  copies of the Software, and to permit persons to whom the Software is
  furnished to do so, subject to the following conditions:

  The above copyright notice and this permission notice shall be included in
  all copies or substantial portions of the Software.

  THE SOFTWARE IS PROVIDED "AS IS", WITHOUT WARRANTY OF ANY KIND, EXPRESS OR
  IMPLIED, INCLUDING BUT NOT LIMITED TO THE WARRANTIES OF MERCHANTABILITY,
  FITNESS FOR A PARTICULAR PURPOSE AND NONINFRINGEMENT. IN NO EVENT SHALL THE
  AUTHORS OR COPYRIGHT HOLDERS BE LIABLE FOR ANY CLAIM, DAMAGES OR OTHER
  LIABILITY, WHETHER IN AN ACTION OF CONTRACT, TORT OR OTHERWISE, ARISING FROM,
  OUT OF OR IN CONNECTION WITH THE SOFTWARE OR THE USE OR OTHER DEALINGS IN
  THE SOFTWARE.
  =========================================================
*/

// I2Cdev and MPU6050 must be installed as libraries
#include <I2Cdev.h>
#include <MPU6050.h>
#include <Wire.h>
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

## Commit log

2018-05-15 add bom for DIY mini
    [miniBOM.csv]
2018-08-10 added some files for servo tests
    [torqueArm.stl]
2018-08-28 rename servoTest as testServo
    [torqueArm.stl]
2018-08-28 update servoTorqueArm
    [servoTorqueArm.stl]
2018-09-17 added some trivial tricks during development. I should save more short codes for idea validation.
    [miniBOM.csv, servoTorqueArm.stl]
2018-11-14 fix naming on Resource folder
    [mg90d.stl, miniBOM.csv]
2018-11-14 rename Resource folder
    [mg90d.stl, miniBOM.csv]
2018-11-20 fixed bugs suggested by Iker De Echaniz(ideechaniz@gmail.com); added jointMap.png
    [Nybble.ino, OpenCat.h, WriteInstinct.ino]
2018-11-20 upper case WriteInstinct/
2018-12-16 modified as sold model and 3D printable
    [mg90d.stl]
2019-01-02 added soldering instruction for ultrasound's LED
2019-01-02 added board name NyBoard in Arduino IDE
2019-01-02 rename resource folder as resources
    [mg90d.stl, miniBOM.csv]
2019-01-05 added wire part
    [mg90d.stl]
2019-01-06 added nybble's joint map on body
2019-01-06 rename jointIndexNybble.png
2019-01-06 added calibration angle diagram
2019-01-17 swapped back shoulder and knee pin map
    [Nybble.ino, OpenCat.h, WriteInstinct.ino]
2019-03-21 added assemblingInstructions.pdf
2019-04-28 Adding Board Manager support
2019-04-28 mistakes in boards.txt
2019-05-06 added note for servo test
2019-05-13 added table of contents;ultrasound wiring
2019-05-21 updated assembling instructions PDF
2019-05-23 added pre-defined pin table in NyBoard doc
2019-05-25 fixed ardSerial for calibration
    [OpenCat.h, ardSerial.py]
2019-05-25 fixed edge case for space in token i and l
    [ardSerial.py]
2019-05-27 tune the voltage watch
2019-05-28 make the print info shorter
    [Nybble.ino, OpenCat.h]
2019-06-04 added asmagill's board manaer
2019-06-04 updated board.txt
2026-08-15 Update README to drive Quaddle Kickstarter prelaunch signups from GitHub
    Adds a Quaddle CTA with dedicated UTM tracking, founder-credibility
    stats, and physical AI education/applications keyword coverage to this
    legacy repo, plus a pointer to OpenCatESP32 for current-gen hardware.
    Also fixes outdated Instagram/YouTube social handles.
2026-08-16 Add direct Amazon buy link for Bittle X
    This legacy repo still carries 1,376+ stars of traffic despite being obsolete. Adds a direct, UTM-tagged Amazon link alongside the existing pointer to OpenCatESP32, so visitors landing here can reach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

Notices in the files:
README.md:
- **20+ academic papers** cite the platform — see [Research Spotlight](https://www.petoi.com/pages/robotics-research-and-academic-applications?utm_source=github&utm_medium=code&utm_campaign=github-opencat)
